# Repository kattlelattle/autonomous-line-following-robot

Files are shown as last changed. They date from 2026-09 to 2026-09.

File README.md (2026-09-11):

# Autonomous Line-Following Robot

Low-cost autonomous line-following robot developed as a University of Toronto ECE summer research project, funded by the First Year Summer Research Fellowship.

<p align="center">
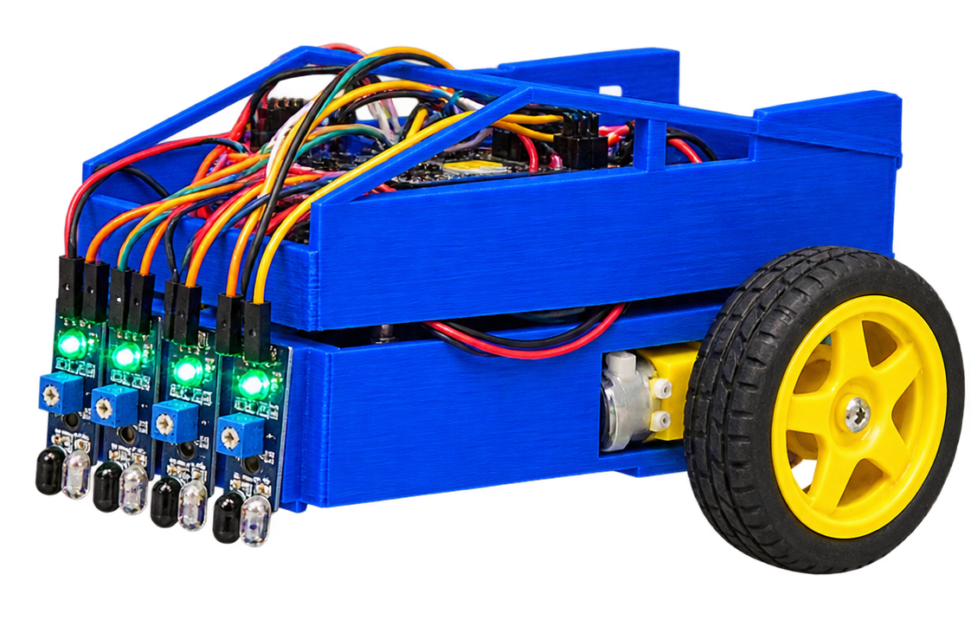
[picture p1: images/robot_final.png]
Final line-following robot
  
</p>

## Demo

[Robot completing test track](https://youtu.be/DiFReegMmhk)

## Overview

The original platform used four continuous-rotation servos. I redesigned it around:

- 2 DC geared motors
- L298N motor driver
- 5-sensor IR array
- passive caster wheel
- custom 3D-printed chassis
- PWM-based steering control

The main design changes were the drivetrain, chassis geometry, caster mounting, and IR sensor placement.

## CAD

<p align="center">
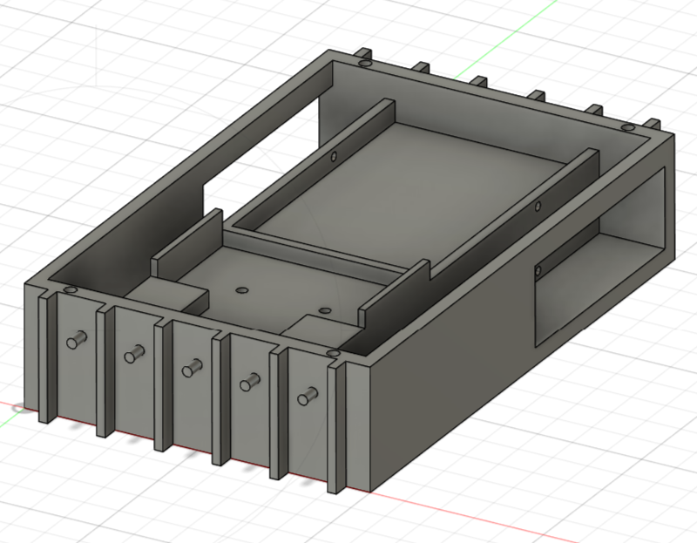
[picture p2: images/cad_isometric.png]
Chassis CAD
  
  &nbsp;&nbsp;
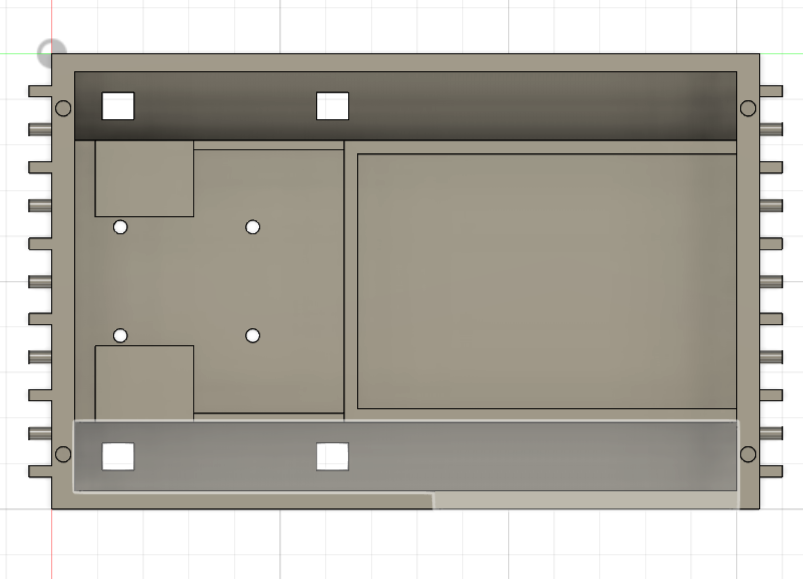
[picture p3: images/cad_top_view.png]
Chassis top view
  
</p>

Final CAD files:

- [`chassis_final.step`](cad/chassis_final.step)
- [`chassis_final.stl`](cad/chassis_final.stl)

## Firmware

The five IR sensors are used to determine the robot's position relative to the line. Motor speeds are adjusted independently using PWM for left/right steering corrections.

Final code: [`line_follower.ino`](firmware/line_follower.ino)

## Testing

Four chassis/sensor configurations were tested with **25 trials each (100 total)**.

| Sensor distance | Chassis | Result |
|---|---|---:|
| 16 mm | Tilted | 7/25 — 28% |
| 16 mm | Level | 13/25 — 52% |
| 139 mm | Tilted | 23/25 — 92% |
| 139 mm | Level | **24/25 — 96%** |

The longer **139 mm sensor look-ahead** produced the largest improvement. The best configuration completed **24/25 trials successfully**.

Raw results: [`trial_results.csv`](testing/trial_results.csv)

## Research Poster

[View the project poster](docs/research_poster.pdf)

Supervised by Professor Hamid Timorabadi, Department of Electrical and Computer Engineering, University of Toronto.

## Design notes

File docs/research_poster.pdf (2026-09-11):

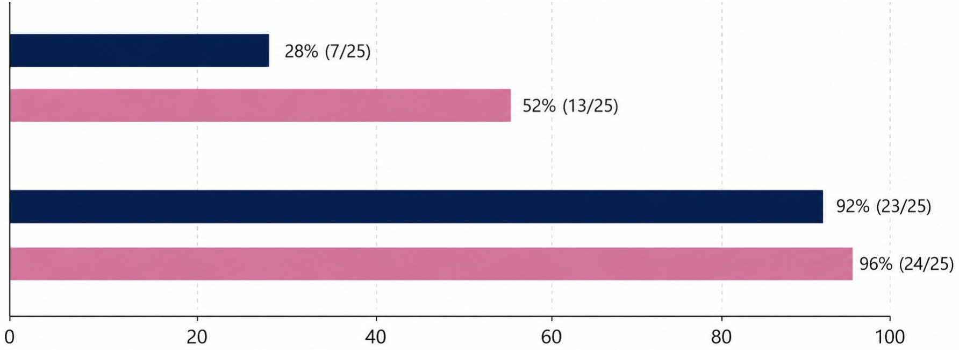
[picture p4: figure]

Iterative design process to improve mechanical fit, caster wheel mounting, sensor placement, and autonomous line tracking.

Track testing procedure (after reliable steering logic):
- 25 trials per configuration under consistent conditions
- Trial considered successful if robot completed the full track without losing the line
- Number of successful trials recorded

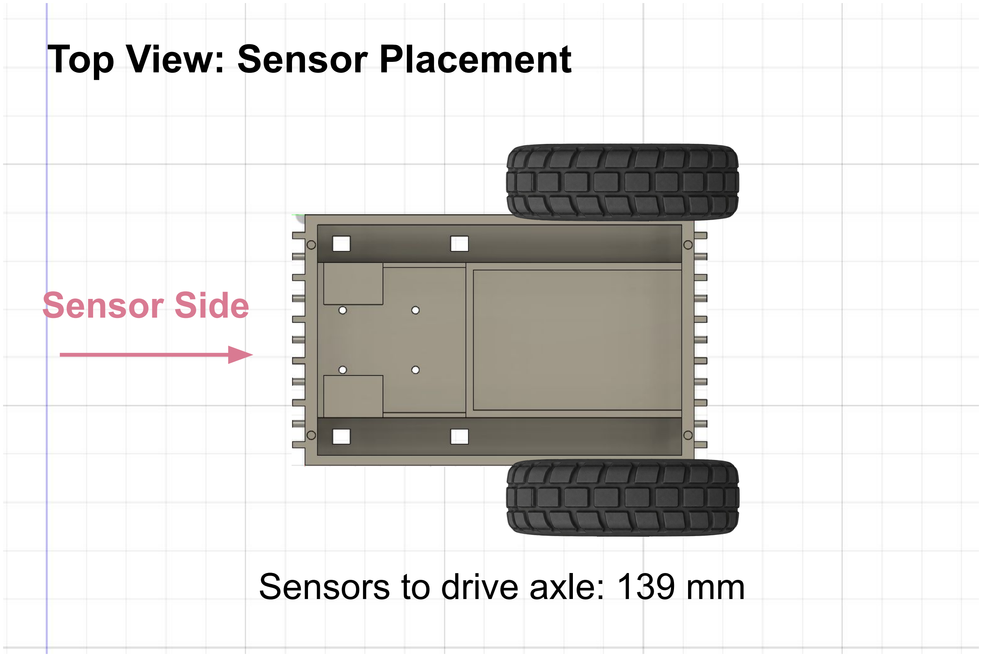
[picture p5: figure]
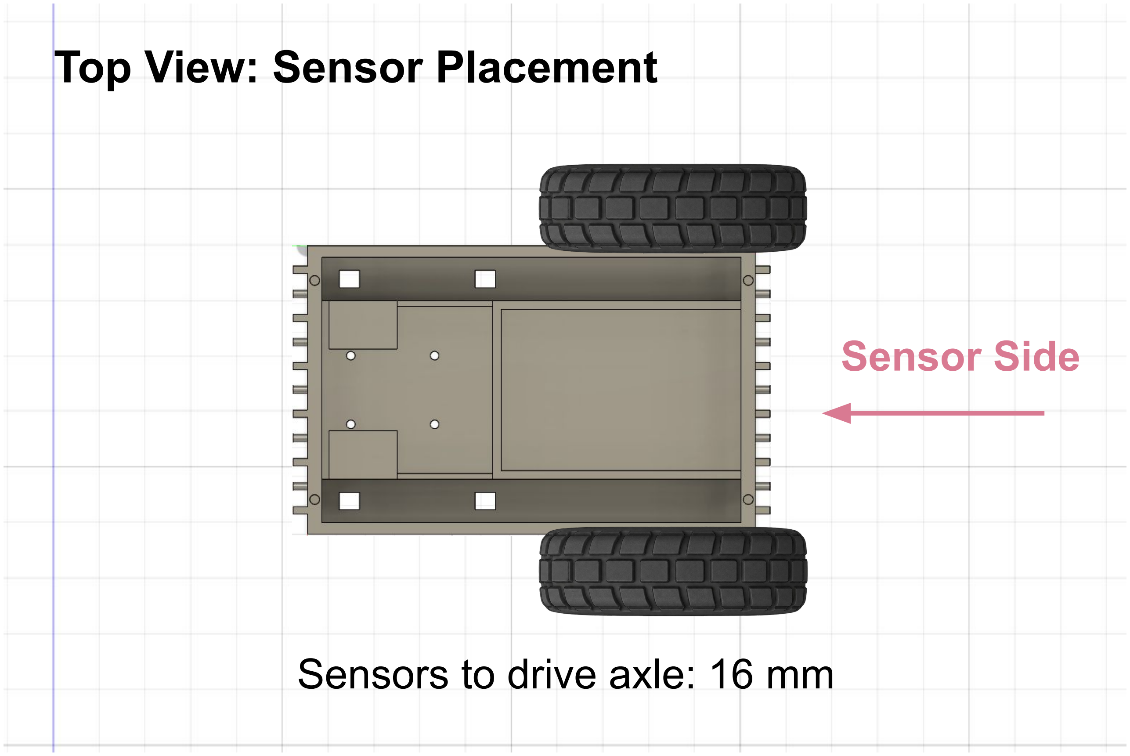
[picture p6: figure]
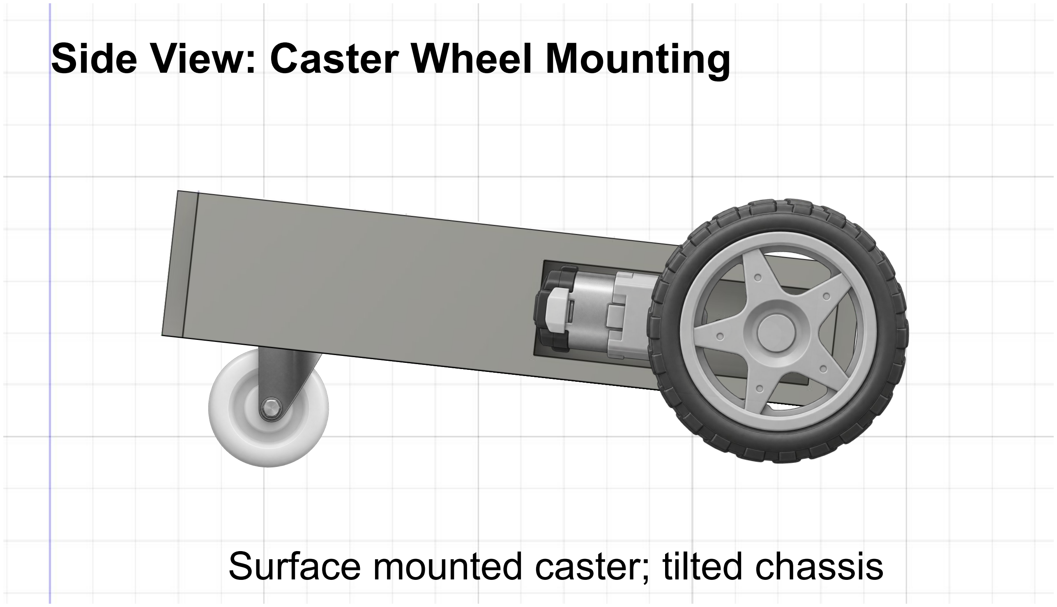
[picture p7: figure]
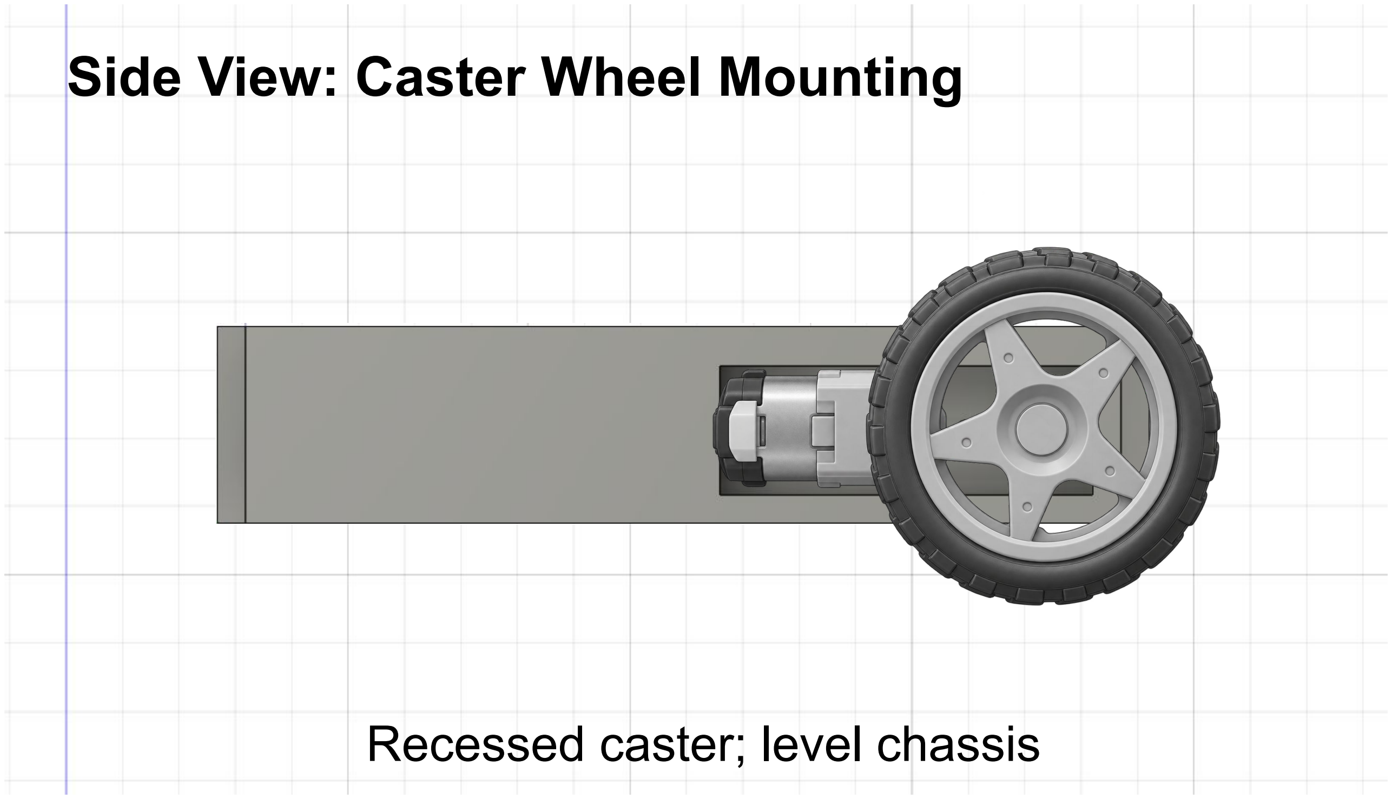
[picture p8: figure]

- Increasing the distance from the sensors to the drive axle from 16 mm to 139 mm improved track completion from 28% to 92% (tilted chassis) and 52% to 96% (level chassis).
- Level configuration outperformed tilted configuration at both sensor positions
- Best configuration: Long look-ahead + level chassis achieved 96% successful autonomous track completion (24/25 trials).

Successful autonomous track completion (%)

# Hardware Redesign and Performance Evaluation of a Low-Cost Autonomous Line-Following Robot

# Katherine Zhang | Supervisor: Professor Hamid Timorabadi Department of Electrical and Computer Engineering, University of Toronto

# Project Overview

# Methods

# Research Question

Results and Discussion | Conclusion

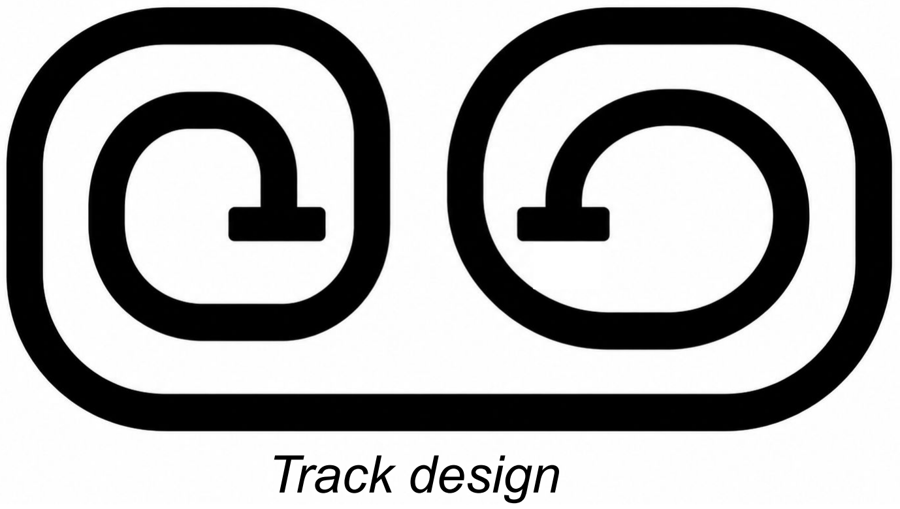
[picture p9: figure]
Track design

# Acknowledgements

The author would like to thank Professor Hamid Timorabadi, the Department of Electrical and Computer Engineering, and the First Year Summer Research Fellowship for their guidance, support, and access to laboratory resources throughout this project.

Autonomous infrared (IR) line-following robots introduce students to sensing, embedded programming, control systems, and mechanical design. Using robotics as a teaching tool can greatly enhance the learning of STEM-related concepts across all levels of education [1].

This project redesigns an existing educational line follower using lower-cost drivetrain components:
- Original: 4 x continuous servos
- Redesigned : 2 x DC geared motors + L298N H-bridge + passive caster wheel

The IR sensor array was repositioned to increase look-ahead distance and improve corrective steering. Previous studies have shown that forward track sensing can help anticipate upcoming curves [2].

How effective is a redesigned chassis in accommodating lower-cost drivetrain components and reliable autonomous line following for future use in first-year ECE workshops?

# Design Variables Evaluated

Sensor Side | Sensor Side
Top View: Sensor Placement | Top View: Sensor Placement
Side View: Caster Wheel Mounting | Side View: Caster Wheel Mounting
Sensors to drive axle: 16 mm | Sensors to drive axle: 139 mm
Surface mounted caster; tilted chassis | Recessed caster; level chassis

Track Completion Performance Across Four Chassis Configurations n = 25 trials per configuration Short look-ahead (16 mm)
Tilted chassis

Level chassis

Long look-ahead (139 mm)
Tilted chassis

Level chassis

# Key Findings

This project demonstrates that lower-cost drivetrain
components can be successfully integrated into an educational autonomous line-following robot. Through both chassis and sensor placement redesigns, the final robot replaces the original four-servo drivetrain with two DC geared motors, a L298N motor driver, and a passive caster wheel to maintain reliable autonomous navigation. Of the four configurations evaluated, the long look-ahead + level-chassis design achieved the highest track completion rate at 96% (24/25 trials). These results support the redesigned robot as a viable lower-cost alternative for next year’s summer ECE workshops.

References

[1] F. B. V. Benitti, “Exploring the educational potential of robotics in schools: A systematic review,” Computers & Education, vol. 58, no. 3, pp. 978–988, 2012, doi: 10.1016/j.compedu.2011.10.006.
[2] A. Roy and M. M. Noel, “Design of a high-speed line following robot that smoothly follows tight curves,” Computers & Electrical Engineering, vol. 56, pp. 732–747, 2016, doi: 10.1016/j.compeleceng.2015.06.014.

# Limitations & Future Work

1) CAD Design | 2) 3D Print | 3) Assemble
6) Design
Revision
4) Test on
Track
5) Identify
Limitations

# PWM Steering Logic

Stronger left correction | Straight
- Testing was limited to a single track design and can be expanded to more complex line patterns.
- Long term performance through repeated workshop use have not yet been evaluated.
- Future work can test different motor speeds and supply voltages to optimize line tracking speed.
Left correction | Right correction
= line detected | = background

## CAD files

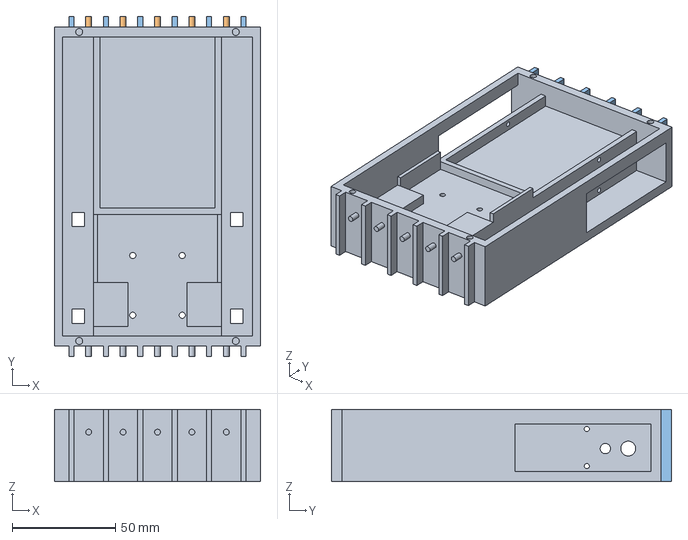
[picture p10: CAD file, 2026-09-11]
cad/chassis_final.step
100.0 x 165.0 x 35.0 mm

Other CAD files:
cad/chassis_final.stl

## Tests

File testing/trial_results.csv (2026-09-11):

sensor_lookahead_mm | chassis | successful_trials | total_trials | completion_rate
16 | tilted | 7 | 25 | 28
16 | level | 13 | 25 | 52
139 | tilted | 23 | 25 | 92
139 | level | 24 | 25 | 96

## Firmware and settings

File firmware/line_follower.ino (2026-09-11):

#define IR_R A0
#define IR_MR A1
#define IR_M A2
#define IR_ML A3
#define IR_L A4

#include <math.h>
#include <Adafruit_MotorShield.h>
#include <stdio.h>

// Motor A
const int ENA = 5;   // PWM
const int IN1 = 6;
const int IN2 = 9;

// Motor B
const int ENB = 10;  // PWM
const int IN3 = 11;
const int IN4 = 12;

void setup() {
  pinMode(ENA, OUTPUT);
  pinMode(IN1, OUTPUT);
  pinMode(IN2, OUTPUT);

  pinMode(ENB, OUTPUT);
  pinMode(IN3, OUTPUT);
  pinMode(IN4, OUTPUT);

  stopMotors();

  pinMode(IR_R, INPUT);
  pinMode(IR_MR, INPUT);
  pinMode(IR_M, INPUT);
  pinMode(IR_ML, INPUT);
  pinMode(IR_L, INPUT);
  
  Serial.begin(9600);
}

void loop() {
  bool r, mr, m, ml, l;
  r = digitalRead(IR_R);
  mr = digitalRead(IR_MR);
  m = digitalRead(IR_M);
  ml = digitalRead(IR_ML);
  l = digitalRead(IR_L);

  Serial.print(r);
  Serial.print(mr);
  Serial.print(m);
  Serial.print(ml);
  Serial.println(l);

  if(!r && !mr && !m && !ml && !l){
    stopMotors();
  }
  else if(r && mr && m && ml && l){
    stopMotors();
  }
  else if(!r && mr && ml && !l){ //forward
    motorA(100);
    motorB(100);
  }
  else if(!r && mr && ml && l){ //left
    motorA(255);
    motorB(20);
  }
  else if(!r && !mr && ml && l){ //sharp left
    motorA(255);
    motorB(0);
  }
  else if(r && ml && !l){ //right
    motorA(20);
    motorB(255);
  }
  else if(r && !ml && !l){ //sharp right
    motorA(0);
    motorB(255);
  }
  else{
    motorA(100);
    motorB(100);
  }
}

void motorA(int speed) {
  if (speed > 0) {
    digitalWrite(IN1, HIGH);
    digitalWrite(IN2, LOW);
    analogWrite(ENA, speed);
  }
  else if (speed < 0) {
    digitalWrite(IN1, LOW);
    digitalWrite(IN2, HIGH);
    analogWrite(ENA, -speed);
  }
  else {
    analogWrite(ENA, 0);
  }
}

void motorB(int speed) {
  if (speed > 0) {
    digitalWrite(IN3, LOW);
    digitalWrite(IN4, HIGH);
    analogWrite(ENB, speed);
  }
  else if (speed < 0) {
    digitalWrite(IN3, HIGH);
    digitalWrite(IN4, LOW);
    analogWrite(ENB, -speed);
  }
  else {
    analogWrite(ENB, 0);
  }
}

void stopMotors() {
  analogWrite(ENA, 0);
  analogWrite(ENB, 0);

  digitalWrite(IN1, LOW);
  digitalWrite(IN2, LOW);
  digitalWrite(IN3, LOW);
  digitalWrite(IN4, LOW);
}

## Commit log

2026-09-11 Add project files
    [chassis_final.step, chassis_final.stl, trial_results.csv]
2026-09-11 Revise README with project details and testing results
    Updated project description, added CAD images, and detailed testing results.
2026-09-11 Add demo section to README
    Added a demo section with a link to a video of the robot completing the test track.
2026-11-09 Add demo link to README
    Added demo link for robot test track video.
